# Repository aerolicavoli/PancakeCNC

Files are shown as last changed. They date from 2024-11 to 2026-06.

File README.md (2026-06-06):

# PancakeCNC

A fully custom, pancake-printing CNC platform. This repository collects the mechanical CAD, controller electronics, firmware, ground station tooling, and reference simulations that work together to lay down batter in precise paths.

## Table of Contents
- [Project Overview](#project-overview)
- [Repository Layout](#repository-layout)
- [Mechanical Platform](#mechanical-platform)
- [Electronics and PCB](#electronics-and-pcb)
- [Firmware (`Pancake_esp`)](#firmware-pancake_esp)
- [Ground Station Tools](#ground-station-tools)
- [Simulation & Analysis](#simulation--analysis)
- [Design Documentation](#design-documentation)
- [Command & Telemetry Protocol](#command--telemetry-protocol)
- [Development Environment](#development-environment)
- [License](#license)

## Project Overview
PancakeCNC is a learning platform for end-to-end mechatronics: mechanical design, PCB layout, embedded firmware, networking, and motion control. The goal is to dispense pancake batter using precise CNC motion profiles driven from a custom controller and cloud-connected command stream.

## Repository Layout
```
ControllerPCB/   KiCad project files for the controller board and manufacturing assets.
DesignDocs/      Engineering notes, diagrams, and BOMs.
GroundStation/   Python-based tooling for sending CNC commands and replaying G-code.
PancakeSim/      MATLAB scripts for kinematic studies and controller validation.
Pancake_esp/     ESP-IDF firmware for the ESP32-S3 based controller.
```

## Mechanical Platform
Motion is handled by a double-jointed planar arm that provides two rotational degrees of freedom so the dispenser can reach any point in the intended print envelope. Batter is metered with a peristaltic pump mounted at the arm's end effector.

The printable CAD for the hinges and pump assembly is currently tracked outside this repository; the focus here is on the control stack that drives the mechanism.

## Electronics and PCB
The `ControllerPCB` directory captures the KiCad design for the controller enclosure. Highlights include:

- ESP32-S3 compute module, GPIO breakout, and headers that feed external step/dir motor drivers sourced from the BOM.
- Power conditioning and 5 V level shifting for peripheral interfaces.
- Ready-to-fabricate assets: schematic (`ControllerPCB.kicad_sch`), layout (`ControllerPCB.kicad_pcb`), and generated BOM/gerbers.

## Firmware (`Pancake_esp`)
Firmware is built with ESP-IDF and lives under `Pancake_esp/`. Key modules:

- **Command Handling** (`CommandHandler.*`, `CNCOpCodes.h`): parses high-level instructions into motion primitives.
- **Motion Control** (`MotorControl.*`, `StepperMotor.*`, `TrapezoidalJog.*`, `ArchimedeanSpiral.*`): generates coordinated movements for the S0/S1 axes and pump.
- **Networking & Telemetry** (`InfluxDBCmdAndTlm.*`, `Telemetry.*`, `WifiHandler.*`): streams commands from InfluxDB and publishes runtime state.
- **Safety & UI** (`Safety.*`, `UI.*`): implements interlocks and emergency stop logic. A dedicated human interface is still a work in progress—commands flow through the InfluxDB bridge today.

To build the firmware you will need the ESP-IDF toolchain (v5.x recommended). After configuring credentials in `sdkconfig`/`Secret.h`, standard `idf.py build flash monitor` targets apply.

### Viewing ESP logs over the flash serial port (macOS)
The firmware keeps ESP-IDF logging active on the default serial sink, so anything emitted with `ESP_LOG*` can be viewed on the same USB serial device used for flashing.

1. List serial devices:
   ```bash
   ls /dev/cu.usb*
   ```
2. Open a monitor (replace the port with your device):
   ```bash
   idf.py -p /dev/cu.usbmodemXXXX monitor
   ```
   If you are outside an ESP-IDF shell, a simple fallback is:
   ```bash
   screen /dev/cu.usbmodemXXXX 115200
   ```
3. Exit monitor:
   - `idf.py monitor`: press `Ctrl+]`
   - `screen`: press `Ctrl+A`, then `K`, then `Y`

## Ground Station Tools
`GroundStation/CommandTerminal.py` is a CLI utility for sending commands through InfluxDB using a human-readable syntax. Example interactions:

```bash
python GroundStation/CommandTerminal.py e "Hello Pancake"
python GroundStation/CommandTerminal.py cnc_spiral CenterX_m=0.2 LinearSpeed_mps=0.05
python GroundStation/CommandTerminal.py run_file GroundStation/GCode/TestProgram.txt
```

Environment variables must be set to connect to InfluxDB:

- `INFLUXDB_URL`
- `INFLUXDB_TOKEN`
- `INFLUXDB_ORG`
- `INFLUXDB_CMD_BUCKET`

`GroundStation/GCode/` contains sample programs for testing complex pours.

## Simulation & Analysis
`PancakeSim/KinematicTestBed.m` is a MATLAB script for exercising the inverse kinematics and closed-loop control algorithms before they are deployed to hardware.

## Design Documentation
`DesignDocs/` aggregates system-level context:

- `DesignDiagrams.drawio` — block diagrams and signal flows.
- `BillOfMaterials.md` — hardware inventory and sourcing notes.
- `Channelization.md` — signal/channel mapping across subsystems.

## Command & Telemetry Protocol
Commands are binary packets exchanged through InfluxDB and consumed by the firmware.

### Frame Layout
| Byte Index | Field | Size | Description |
|---|---|---|---|
| `[0]` | **Op Code** | 1 byte | Instruction identifier |
| `[1]` | **Length** | 1 byte | Number of payload bytes (*n*) |
| `[2..n+1]` | **Payload** | *n* bytes | Instruction-specific data |

### Firmware Opcodes
Immediate commands bypass the CNC queue:

- `0x01` — `pause`
- `0x02` — `resume`
- `0x03` — `stop`
- `0x69` — `echo`

Queued motion & configuration commands include:

- `0x11` — `cnc_spiral`
- `0x12` — `cnc_jog`
- `0x13` — `wait`
- `0x14` — `cnc_sine`
- `0x15` — `cnc_constant_speed`
- `0x16` — `set_motor_limits`
- `0x17` — `set_pump_constant`
- `0x18` — `cnc_arc`
- `0x19` — `pump_purge`

Payloads are little-endian C structs (refer to headers under `Pancake_esp/main/`). The CLI automatically translates key-value inputs into the correct binary layouts. `pump_purge` accepts a signed `pumpSpeed_degps`; use a negative value, such as `pump_purge pumpSpeed_degps=-300 duration_ms=500`, to reverse the pump and pull batter back before stopping.

### Round-Trip Testing
`GroundStation/RoundtripTest.py` can send a command and fetch the recorded response, verifying connectivity and serialization. If environment variables are missing it will attempt to source `Secret.sh`.

## Development Environment
- **Firmware**: ESP-IDF (requires Python, CMake, Ninja). Install dependencies per Espressif documentation.
- **Ground Station**: Python 3.10+. Install requirements (if a `requirements.txt` is added) or run directly with the standard library and `influxdb-client`.
- **Mechanical/Electrical CAD**: KiCad 7.x for PCB edits, CAD/CAM packages for STL manipulation.

## License
This project is currently distributed without an explicit license; treat the assets as freely reusable unless noted otherwise in specific subdirectories.

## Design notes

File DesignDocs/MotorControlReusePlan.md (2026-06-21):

# Motor Control Complexity and Reuse Improvement Plan

## Purpose

`MotorControlTask` currently combines queue handling, command decoding, guidance selection, motion solving, pump control, stop handling, motor output, limit switch handling, and telemetry publication in one long control loop. The goal of this plan is to keep the timing-critical loop small and predictable while moving reusable policies into focused components that can be tested without FreeRTOS or motor hardware.

## Current Complexity Drivers

1. **Many responsibilities in one task**
   - The task owns immediate command handling, queued configuration commands, motion opcode dispatch, target generation, cartesian-to-angle conversion, speed limiting, pump decisions, telemetry copies, and limit switch reactions.
   - Safety hold behavior is repeated in multiple branches, including explicit stop handling and out-of-bounds handling.

2. **Implicit shared state**
   - Loop state is spread across local variables (`instructionComplete`, `pumpThisMode`, `cmdViaAngle`, purge fields, target angles, target position, commanded speeds) and globals (`Pos_m`, `Vel_mps`, `Target_m`, telemetry data, `CNCEnabled`, `EStopActive`).
   - It is difficult to determine which fields must be reset when a command completes, pauses, stops, faults, or trips a limit switch.

3. **Opcode dispatch is repetitive**
   - Each guidance command repeats the same payload-length validation, `memcpy`, `ApplyConfig`, `currentGuidance` assignment, pump flag handling, and logging pattern.
   - Adding a new motion type requires editing the central switch and risks changing unrelated behavior.

4. **Hardware and policy are tightly coupled**
   - Speed computation, pump flow policy, and limit switch behavior are interleaved with direct `StepperMotor` calls and FreeRTOS queues.
   - This limits reuse from host-side tests and makes regression tests harder to write.

5. **Mixed coordinate command paths**
   - Cartesian guidance and angle guidance share state but diverge late in the loop.
   - Angle-specific completion and speed limiting for go-to-angle is embedded in the task instead of being a reusable angle-mode controller.

## Target Design

Refactor toward a small orchestration loop backed by reusable components:

```text
MotorControlTask
  ├── MotorControlState          // all mutable loop state in one struct
  ├── MotorCommandRouter         // now queue + cnc queue classification
  ├── GuidanceRegistry           // opcode -> typed guidance adapter
  ├── MotionPlanner              // target -> motor angle/speed command
  ├── PumpController             // print-flow and purge policy
  ├── SafetyHoldController       // pause/stop/fault/limit switch holds
  ├── MotorDriverSet             // S0/S1/pump StepperMotor facade
  └── TelemetryPublisher         // copies a state snapshot to telemetry
```

The end state should let `MotorControlTask` read telemetry, route commands, ask the active guidance for a target, ask the planner and pump controller for commands, apply safety overrides, write motor outputs, publish telemetry, and sleep.

## Behavior That Must Be Preserved

- Jog commands must remain able to request motion either with the pump on or with the pump off. The refactor should keep `CNC_JOG_OPCODE`'s `PumpOn` payload field as an explicit per-command policy, not collapse jog into a single default pump behavior.

## Refactoring Principles

- **Keep behavior-preserving steps small.** Each phase should compile and run tests before moving to the next phase.
- **Introduce seams before changing behavior.** First move existing code into functions/classes with equivalent inputs and outputs; then improve internals.
- **Prefer data ownership over parallel variables.** Replace groups of related locals with named structs and reset/apply helper functions.
- **Make policies host-testable.** Components that do not require ESP-IDF or GPIO should live behind simple interfaces and have unit tests under `Tests/`.
- **Use adapters for legacy guidance classes.** Avoid rewriting all guidance classes at once; wrap them in a common registry/factory pattern. Adapter metadata should preserve command-specific options such as jog's pump-on/pump-off selection.
- **Centralize stop/hold semantics.** All pause, stop, fault, unreachable-target, and limit-switch paths should share one hold command application path.

## Phased Plan

### Phase 1: Name and isolate loop state

1. Add a `MotorControlState` struct that owns the current position, velocity, target position, target angles, commanded speeds, active guidance pointer, completion flag, pump mode, purge state, command mode, pause state, and force-update flag.
2. Move repeated application of `MotionHoldCommand` into a single `ApplyHoldCommand(MotorControlState&, const MotionHoldCommand&)` helper.
3. Replace scattered local resets with state methods such as `IdleAtCurrentPosition(...)`, `StopPurge()`, and `CompleteInstruction()`.
4. Keep the existing globals as compatibility aliases initially, but update them from the state snapshot in one place.

**Success criteria**
- The main task has fewer independent local variables.
- Stop and out-of-bounds paths call the same hold-application helper.
- Existing behavior remains unchanged.

### Phase 2: Extract command routing and configuration handling

1. Create a `MotorCommandRouter` with methods for:
   - consuming immediate pause/resume/stop commands;
   - draining queued CNC commands when requested;
   - consuming non-motion configuration commands at the head of the CNC queue;
   - returning the next motion command only when the controller is ready.
2. Move config-command handlers into named methods (`ApplyMotorLimits`, `ApplyPumpConstant`, `ApplyAccelScale`, `StartPumpPurge`) with explicit payload validation.
3. Define a small `MotorControlConfig` struct for tunable values such as `pumpConstant_degpm`, `accelScale`, and position tolerance.
4. Validate payload lengths against command-specific expected sizes rather than open-ended checks where possible, unless a command intentionally supports extension.

**Success criteria**
- The task loop no longer contains queue peeking/parsing details.
- Config behavior is independently testable with synthetic payloads.
- Unknown or malformed commands produce one consistent error path.

### Phase 3: Replace central opcode switch with a guidance registry

1. Introduce a `GuidanceRegistry` that owns the existing guidance instances and maps each opcode to a descriptor:
   - opcode;
   - expected payload size;
   - pump policy source (`AlwaysOff`, `AlwaysOn`, or `FromPayload`);
   - typed apply function;
   - pointer/reference to the guidance object.
2. Factor the repeated validate/copy/apply/start pattern into one generic command loader.
3. Preserve special cases, such as jog's `PumpOn` flag and go-to-angle's angle-command mode, in the descriptor/adaptor instead of the main loop.
4. Add a lightweight unit test that submits representative opcode payloads and verifies the selected guidance, command mode, and pump policy. Include both `PumpOn=0` and `PumpOn=1` jog payloads.

**Success criteria**
- Adding a guidance type requires adding a descriptor and guidance instance, not editing a large switch.
- Payload validation and logging are uniform for all guidance commands.
- `MotorControlTask` only asks the registry to start a motion command.

### Phase 4: Extract motion planning

1. Create a `MotionPlanner` with explicit input and output structs:
   - inputs: current motor telemetry, current cartesian state, target position, guidance command mode, active guidance metadata, limits, accel scale;
   - outputs: target angles, S0/S1 commanded speeds, instruction-complete override, hold/fault request.
2. Move `WrapAngleDeltaDeg` and `ComputeDecelLimitedSpeedDegps` into the planner or a reusable motion math module.
3. Split planning by mode:
   - `PlanCartesianTarget` performs `CartToAng`, reachability checks, and speed limiting;
   - `PlanAngleTarget` handles go-to-angle target angles, tolerance, completion, and speed limiting;
   - `PlanIdleHold` generates zero-speed angle-mode hold commands.
4. Represent reachability failures as a planner status instead of stopping directly inside planning code; the task or safety controller applies the hold.

**Success criteria**
- Cartesian and angle command paths are explicit and separately testable.
- Out-of-bounds handling reuses the same stop/hold path as immediate stop.
- Speed limiting can be validated with host-side tests.

### Phase 5: Extract pump policy

1. Create a `PumpController` that owns purge state and computes pump speed from:
   - emergency-stop state;
   - instruction-active state;
   - active command pump policy, including jog's per-command pump-on/pump-off choice;
   - target error magnitude;
   - current cartesian velocity;
   - configured pump constant.
2. Give purge override a clear priority over normal print-flow mode while still respecting pause/stop.
3. Replace bare purge locals with methods such as `StartPurge(speed, duration)`, `CancelPurge()`, and `Update(period_ms)`.
4. Add tests for normal printing, no-pump modes, position tolerance gating, purge timeout, and pause cancellation.

**Success criteria**
- Pump behavior is no longer interleaved with cartesian planning.
- Pump policy can be reused by future print modes without touching motor planning, while still allowing jogs to choose whether they dispense.
- Purge state transitions are covered by tests.

### Phase 6: Isolate motor hardware access

1. Create a `MotorDriverSet` facade around S0, S1, and pump motors.
2. Move repeated target-speed and update-speed calls into `ApplyMotorSpeeds(const MotorSpeedCommand&, bool forceUpdate)`.
3. Move motor limit updates into facade methods that accept motor IDs and all-motors broadcasts.
4. Add a fake motor-driver implementation for unit tests, or define a minimal interface where host tests can assert commanded speeds without ESP timers.

**Success criteria**
- Motor output application is one method call from the task loop.
- Config commands no longer capture concrete `StepperMotor` objects in local lambdas.
- Host tests can exercise router/planner/controller code without real motors.

### Phase 7: Centralize telemetry publishing and synchronization

1. Create a `TelemetryPublisher` that takes a `MotorControlState` snapshot and motor telemetry snapshot.
2. Keep all writes to `TelemetryData` in one function.
3. Decide whether telemetry needs a FreeRTOS critical section, mutex, or double-buffered snapshot, then apply it in the publisher only.
4. Include pause/active-guidance/pump-purge status fields if the telemetry model supports them later.

**Success criteria**
- The task loop no longer manually copies every telemetry field.
- Thread-safety changes are isolated to one publisher.
- Future telemetry fields can be added without changing planning logic.

### Phase 8: Limit switch and safety integration

1. Move limit switch handling into `SafetyHoldController` or a dedicated `LimitSwitchController`.
2. Make the limit-switch result explicit: directional inhibit, zero request, instruction-complete request, and optional queue drain/fault state.
3. Use the same state transition methods for limit-switch stops as for pause/stop/faults.
4. Add tests that assert the correct motor receives the correct directional inhibit and zero request.

**Success criteria**
- Limit switch policy is not mixed with telemetry publication.
- Every safety-related transition has one clearly named path.
- Safety behavior can be reviewed without reading the entire motor loop.

## Suggested Intermediate File Layout

```text
Pancake_esp/main/
  MotorControl.cpp              // short FreeRTOS orchestration task
  MotorControl.h
  MotorControlState.h           // state and command structs
  MotorCommandRouter.h/.cpp     // queue parsing and command classification
  GuidanceRegistry.h/.cpp       // opcode-to-guidance adapters
  MotionPlanner.h/.cpp          // reusable target/speed planning
  PumpController.h/.cpp         // reusable pump and purge policy
  MotorDriverSet.h/.cpp         // StepperMotor facade
  TelemetryPublisher.h/.cpp     // TelemetryData snapshot writes
```

Start with header-only structs and small `.cpp` files only where necessary. If ESP-IDF include dependencies make host tests hard, keep pure policy headers free of FreeRTOS and GPIO headers.

## Testing Strategy

1. **Host unit tests first**
   - Add tests for `ComputeDecelLimitedSpeedDegps`, angle wrapping, cartesian reachability status, pump purge timing, and command payload validation.
2. **Regression tests around existing guidance**
   - Use existing guidance classes directly to verify registry selection does not alter target generation.
3. **Fake queue and fake motor tests**
   - Test command routing and motor output application without FreeRTOS timers or GPIO.
4. **On-device smoke tests after each major phase**
   - Pause/resume/stop.
   - Jog with pump off/on.
   - Spiral/arc/rectangle print commands.
   - Go-to-angle completion tolerance.
   - Pump purge during idle and during active motion.
   - Limit switch trip and reset behavior.

## Recommended Implementation Order

1. `MotorControlState` and hold-command application helper.
2. `PumpController`, because it is low-risk and easy to test.
3. `MotionPlanner`, because it removes the highest-risk math from the task loop.
4. `GuidanceRegistry`, because it reduces opcode-switch churn after planner seams exist.
5. `MotorCommandRouter`, because it becomes simpler once config and motion targets have homes.
6. `MotorDriverSet` and `TelemetryPublisher`, because these are mostly integration cleanup.
7. `LimitSwitchController`/safety cleanup, after the hold path is proven.

## Risks and Mitigations

- **Risk: behavior changes during extraction.** Mitigate by snapshotting current behavior with tests before changing policy internals.
- **Risk: ESP-IDF dependencies leak into host tests.** Mitigate with pure data structs and facades around queues, GPIO, and `StepperMotor`.
- **Risk: registry descriptors hide important special cases.** Mitigate by making special policy fields explicit (`pumpPolicy`, `commandMode`, `completionPolicy`) and testing each opcode.
- **Risk: too many tiny classes too early.** Mitigate by extracting functions and structs first, then promoting them to classes only when there is clear state or interface ownership.

## Definition of Done

The refactor is complete when:

- `MotorControlTask` is primarily orchestration and fits on one screen or close to it.
- All pause/stop/fault/limit-switch holds share one state transition path.
- Adding a new guidance opcode does not require duplicating payload-validation boilerplate.
- Motion math and pump policy have host-side unit coverage.
- Motor hardware access and telemetry writes are isolated behind narrow interfaces.
- Existing on-device motion behavior is preserved unless a change is intentionally documented.

## Refactor Progress

This checklist tracks what has actually been completed in code, not just what has been planned.

- [x] **Phase 1: Name and isolate loop state** — Complete.
  - [x] Added `MotorControlState` to own current position, velocity, target position, target angles, commanded speeds, active guidance, completion state, pump state, purge state, command mode, pause state, and force-update state.
  - [x] Added shared state helpers, including `ApplyHoldCommand`, `IdleAtCurrentPosition`, `StopPurge`, `CompleteInstruction`, and `StartInstruction`.
  - [x] Replaced repeated stop/out-of-bounds hold assignments with the shared hold application path.
  - [x] Kept existing position/target/pause globals synchronized from the state snapshot for compatibility.
- [x] **Phase 2: Extract command routing and configuration handling** — Complete.
  - [x] Added `MotorCommandRouter` to consume immediate pause/resume/stop commands, drain the CNC queue, consume head-of-queue configuration commands, and return the next motion command only when the state is ready.
  - [x] Moved configuration handlers into named router methods for motor limits, pump constant, acceleration scale, and pump purge.
  - [x] Added `MotorControlConfig` for tunable pump constant, acceleration scale, and position tolerance.
  - [x] Configuration handlers now validate command-specific payload lengths exactly before applying payload contents.
- [x] **Phase 3: Replace central opcode switch with a guidance registry** — Complete.
  - [x] Added `GuidanceRegistry` with opcode descriptors, expected payload sizes, typed apply functions, guidance pointers, explicit pump policy sources, and command-mode metadata.
  - [x] Replaced the repeated guidance payload validate/copy/apply/start switch with a generic registry loader in `MotorControlTask`.
  - [x] Preserved jog pump selection by resolving `CNC_JOG_OPCODE` pump behavior from the `JogConfig::PumpOn` payload field, including both pump-off and pump-on unit coverage.
  - [x] Moved command-mode selection into registry metadata so go-to-angle, sine, and constant-speed commands are started as angle-mode commands by descriptor rather than by switch-case side effect.
  - [x] Added unit coverage for registry selection, pump policy, command-mode metadata, invalid payload length handling, and unknown opcode handling.
- [ ] **Phase 4: Extract motion planning** — Not started. Cartesian-to-angle conversion, reachability handling, and angle-mode speed limiting still live in `MotorControlTask`.
- [ ] **Phase 5: Extract pump policy** — Not started. Normal pump-speed calculation and purge timing still live in `MotorControlTask`, although Phase 3 now makes the active command's pump-policy source explicit.
- [ ] **Phase 6: Isolate motor hardware access** — Not started. Motor speed commands and limit updates still call `StepperMotor` directly from the task/router integration.
- [ ] **Phase 7: Centralize telemetry publishing and synchronization** — Not started. Telemetry writes are still performed directly in the task loop.
- [ ] **Phase 8: Limit switch and safety integration** — Not started. Limit switch handling is still interleaved with telemetry and motor-control logic.

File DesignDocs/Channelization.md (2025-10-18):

# Pancake CNC – Channelization Rev2

This document describes the channelization for the Pancake CNC.
It details signal routing from the CNC controller, through the PCB,  
through ports on the PCB, and to the end effectors.

This pertains to the second revision of the Pancake CNC PCB.

---

| End User | Direction | PCB Port | Box Port | Corrected Box Port Position | Position | Internal Wire | Conditioning | ESP32 Pin | ESP32 Pin Function | Pi PIN |
|:---|:---|:---|:---|:---|:---|:---|:---|:---|:---|:---|
| Servo Control | Output | Aux DSub (Warning, flipped connector) | DSUB7 | 8 | 7 | Brown | 5V Level Shift | GPIO12 | | |
| S1 Limit | Input | Aux DSub (Warning, flipped connector) | DSUB1 | 5 | 1 | Blue Stripe | None | GPIO15 | | |
| S0 Limit | Input | Aux DSub (Warning, flipped connector) | DSUB3 | 3 | 3 | Green Strip | None | GPIO16 | | |
| Pump Pulse | Output | JST to Driver Zone | | | 1 | | None | GPIO04 | pulse | |
| Pump Dir | Output | JST to Driver Zone | | | 2 | | None | GPIO05 | dir | |
| Pump Enable | Output | JST to Driver Zone | | | 3 | | None | GPIO06 | enable | |
| S0 Pulse | Output | JST to Driver Zone | | | 4 | | None | GPIO07 | pulse | |
| S0 Dir | Output | JST to Driver Zone | | | 5 | | None | GPIO08 | dur | |
| S1 Pulse | Output | JST to Driver Zone | | | 6 | | None | GPIO09 | pulse | |
| S1 Dir | Output | JST to Driver Zone | | | 7 | | None | GPIO10 | dir | |
| S0/S1 Enable | Output | JST to Driver Zone | | | 8 | | None | GPIO14 | enbable | |
| Input Pot X | Input | JST to UI Zone | | | | | None | GPIO01 | ADC1_CH0 | |
| Input Pot Y | Input | JST to UI Zone | | | | | None | GPIO02 | ADC1_CH1 | |
| Flip Switch 1 | Output | JST to UI Zone | | | | | | GPIO18 | | |
| Control Box LED Address | Output | JST to UI Zone | | | | | 5V Level Shift | GPIO21 | | |
| Flip Switch 2 | Output | JST to UI Zone | | | | | | GPIO38 | | |
| Flip Switch 3 | Output | JST to UI Zone | | | | | | GPIO45 | | |
| Flip Switch 4 | Output | JST to UI Zone | | | | | | GPIO46 | | |
| Flip Switch 5 | Output | JST to UI Zone | | | | | | GPIO47 | | |
| Flip Switch 6 | Output | JST to UI Zone | | | | | | GPIO48 | | |
| Control Box Temp | Input | None | | | | | | GPIO03 | ADC1_CH3 | |
| PCB Alive LED | Output | None | | | | | None | GPIO17 | | |
| Pi Serial Data In | Input | Pi JST | | | 1 | | | GPIO11 | FSPID | |
| Pi Serial Data Out | Serial | Pi JST | | | 2 | | | GPIO13 | FSPIQ | |
| Reserved | Reserved | Pi JST | | | 3 | | | GPIO18 | | |
| S0 White | Output | Motor Control DSub | DSUB15 | | 15 | Blue Stripe | | S0B+ | | |
| S0 Black | Output | Motor Control DSub | DSUB15 | | 14 | Blue Solid | | S0A- | | |
| S0 Red | Output | Motor Control DSub | DSUB15 | | 13 | Brown Stripe | | S0B- | | |
| S0 Green | Output | Motor Control DSub | DSUB15 | | 12 | Brown Solid | | S0A+ | | |
| Pump White | Output | Motor Control DSub | DSUB15 | | 11 | Blue Stripe | | PumpB+ | | |
| Pump Black | Output | Motor Control DSub | DSUB15 | | 10 | Blue Solid | | PumpA- | | |
| Pump Red | Output | Motor Control DSub | DSUB15 | | 6 | Brown Stripe | | PumpB- | | |
| Pump Green | Output | Motor Control DSub | DSUB15 | | 5 | Brown Solid | | PumpA+ | | |
| S1 White | Output | Motor Control DSub | DSUB15 | | 4 | Blue Stripe | | S1B+ | | |
| S1 Black | Output | Motor Control DSub | DSUB15 | | 3 | Blue Solid | | S1A- | | |
| S1 Red | Output | Motor Control DSub | DSUB15 | | 2 | Brown Stripe | | S1B- | | |
| S1 Green | Output | Motor Control DSub | DSUB15 | | 1 | Brown Solid | | S1A+ | | |
| Ground | | Aux DSub (Warning, flipped connector) | DSUB2 | 4 | 2 | Blue Solid | | | | |
| Ground | | Aux DSub (Warning, flipped connector) | DSUB4 | 2 | 4 | Green Solid | | | | |
| Ground | | Aux DSub (Warning, flipped connector) | DSUB9 | 6 | 9 | Orange Stripe | | | | |
| Reserved | | Aux DSub (Warning, flipped connector) | DSUB5 | 1 | 5 | | | | | |
| Reserved | | Aux DSub (Warning, flipped connector) | DSUB6 | 9 | 6 | | | | | |
| 5V Servo Power | Output | Aux DSub (Warning, flipped connector) | DSUB8 | 7 | 8 | Orange Solid | | | | |

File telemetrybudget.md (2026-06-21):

# Telemetry Budget

This document summarizes the registered telemetry points, their update rates, and the expected InfluxDB line-protocol payload size per transmit period.

## Scheduling model

Telemetry aggregation runs once every `BUFFER_ADD_PERIOD_MS` (`1000 ms`, or `1 Hz`). The transmit task runs every `TRANSMITPERIOD_MS` (`900 ms`) and sends whatever has accumulated in the working telemetry buffer since the previous transmit attempt.

Each telemetry point is registered with its own period. There are no separate runtime buckets; the aggregate task walks the registry and publishes any point whose configured period has elapsed.

Log lines are also added to the same telemetry buffer when present, but they are event-driven and are **not** included in the fixed-rate budget below.

## Fixed-rate telemetry points

| Rate | Period | Points | Measurements |
| --- | ---: | ---: | --- |
| `1 Hz` | `1000 ms` | 10 | `tipPos_X_m`, `tipPos_Y_m`, `targetPos_X_m`, `targetPos_Y_m`, `S0_Speed_degps`, `S0_TargetSpeed_degps`, `S1_Speed_degps`, `S1_TargetSpeed_degps`, `Pump_Speed_degps`, `Pump_TargetSpeed_degps` |
| `0.25 Hz` | `4000 ms` | 8 | `targetPos_S0_deg`, `targetPos_S1_deg`, `plannedTarget_S0_deg`, `plannedTarget_S1_deg`, `plannedDelta_S0_deg`, `plannedDelta_S1_deg`, `S0_Pos_deg`, `S1_Pos_deg` |
| `0.05 Hz` | `20000 ms` | 13 | `espTemp_C`, `limitBlocked_S0`, `limitBlocked_S1`, `S0_LimitSwitch`, `S1_LimitSwitch`, `cartesianBoundaryCorner0_X_m`, `cartesianBoundaryCorner0_Y_m`, `cartesianBoundaryCorner1_X_m`, `cartesianBoundaryCorner1_Y_m`, `cartesianBoundaryCorner2_X_m`, `cartesianBoundaryCorner2_Y_m`, `cartesianBoundaryCorner3_X_m`, `cartesianBoundaryCorner3_Y_m` |

## Size assumptions

The fixed-rate byte estimates assume the current line protocol format:

```text
<measurement>,location=us-midwest data=<value> <timestamp>\n
```

Assumptions used for the estimate:

- `<value>` is formatted by `%.5f`; the estimate uses `0.00000` (`7` bytes). Negative values or values with more integer digits add bytes.
- `<timestamp>` is a 13-digit millisecond timestamp.
- One newline is included per telemetry point.
- HTTP headers, TLS overhead, TCP/IP framing, and event-driven log telemetry are excluded.

## Payload budget by cadence

| Cadence contribution | Points | Bytes per cadence event | Average bytes per second |
| --- | ---: | ---: | ---: |
| `1 Hz` points | 10 | ~632 B every 1 s | ~632.00 B/s |
| `0.25 Hz` points | 8 | ~514 B every 4 s | ~128.50 B/s |
| `0.05 Hz` points | 13 | ~915 B every 20 s | ~45.75 B/s |
| **Total fixed-rate average** | 31 | N/A | **~806.25 B/s** |

## Expected bytes per transmit period

Because the transmit task runs every `900 ms` and aggregation runs every `1000 ms`, not every transmit tick contains a new aggregate sample. Over a long-running average, fixed-rate telemetry produces:

```text
806.25 B/s * 0.9 s/transmit period = ~725.6 B/transmit period
```

Representative fixed-rate transmit payloads are:

| Transmit payload case | Approximate payload bytes | Notes |
| --- | ---: | --- |
| Empty fixed-rate transmit | 0 B | Possible when the 900 ms transmit task wakes before a new 1000 ms aggregate cycle has added data. |
| 1 Hz-only aggregate | ~632 B | Most aggregate cycles. |
| 1 Hz + 0.25 Hz aggregate | ~1,146 B | Every 4 seconds. |
| 1 Hz + 0.25 Hz + 0.05 Hz aggregate | ~2,061 B | Every 20 seconds, when all registered periods align. |

The fixed telemetry buffer size is `6000 B` with a warning threshold of `5500 B`, so the largest fixed-rate aligned payload is currently about `2.1 kB`, leaving roughly `3.9 kB` of buffer headroom for queued log lines and larger-than-assumed numeric values.

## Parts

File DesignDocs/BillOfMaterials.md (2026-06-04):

# Pancake CNC – Bill of Materials (BOM)

This document lists the **Bill of Materials (BOM)** for the Pancake CNC project.  
It includes all electrical, mechanical, and structural components required for assembly.  
Each line details part numbers, sources, quantities, and other relevant specifications.

---

| Pump | Notes | Source URL |
|:---|:---|:---|
| Part | Quantity | Source |
| tubing | 2 | https://www.mcmaster.com/5894K37/ |
| m3x10 | | https://www.mcmaster.com/91290A115/ |
| m4x20 | | |
| Bearings | 5 | https://www.servocity.com/1600-series-non-flanged-ball-bearing-4mm-id-x-16mm-od-4mm-thickness-2-pack/ |
| hub | | https://www.servocity.com/1314-series-steel-set-screw-hub-5mm-bore/ |
| Spacers | | https://www.servocity.com/1502-series-4mm-id-spacer-6mm-od-1mm-length-4-pack/ |
| Stepper | 1 | https://www.mcmaster.com/4798n12/ |
| CNC | | |
| Part | Quantity | Source |
| 30x30 | 1 | https://8020.net/30-3030.html |
| 60x30 | 1 | https://8020.net/30-3060.html |
| corner bracket | 2 | https://8020.net/30-4303.html |
| tlsot bracket | 2 | https://8020.net/30-4305.html |
| tslot 2x2 | 2 | https://8020.net/30-4367.html |
| NEMA-17 Motor Mount | 2 | https://www.amazon.com/Mrosnail-Stepper-Motor-Mounting-Bracket/dp/B0CRQCT8J5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 |
| fixed pulley | 1 | https://www.mcmaster.com/1277N51/ |
| motor gear | 1 | https://www.mcmaster.com/2664N334/ |
| stepper motor | 2 | https://www.mcmaster.com/4798N12/ |
| Cable ties | 6 | https://www.mcmaster.com/5537T835/ |
| t nuts | 5 | https://www.mcmaster.com/6000N201/ |
| m4 nut | 1 | https://www.mcmaster.com/90592A090/ |
| m4 x 10mm | 1 | https://www.mcmaster.com/92095A190/ |
| Threaded insert | 2 | https://www.mcmaster.com/94459A422/ |
| Bearings | 2 | https://www.servocity.com/1-4-id-x-3-8-od-flanged-ball-bearing-2-pack/ |
| short chan | 1 | https://www.servocity.com/1120-series-u-channel-1-hole-48mm-length/ |
| long chan | 1 | https://www.servocity.com/1121-series-low-side-u-channel-9-hole-240mm-length/ |
| Gussets | 3 | https://www.servocity.com/1204-series-gusseted-angle-mount-1-1-2-pack/ |
| Hub | 2 | https://www.servocity.com/1314-series-steel-set-screw-hub-1-4-bore/ |
| fixed gear | 1 | https://www.servocity.com/2302-series-aluminum-mod-0-8-hub-mount-gear-14mm-bore-108-tooth/ |
| motor pulley | 1 | https://www.servocity.com/5mm-10-tooth-pinion-pulley/ |
| 1/4in shaft | | |
| 1/4 in collars | | |
| Stop Tower | 1 | https://www.servocity.com/1109-series-gorail-120mm-length/ |
| timing belt | 1 | https://www.servocity.com/8-40t-3-8-wide-xl-timing-belt/ |
| Avionics | | |
| Part | Quantity | Source |
| Motor driver | 3 | https://www.amazon.com/UsongShine-Stepper-Controller-Arduino-Printer/dp/B07HHS14VQ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 |
| limit switches | 2 | |
| Flight computer | 1 | |
| Avionics box | | amazon.com/dp/B0CTJX2Q43?ref=ppx_yo2ov_dt_b_fed_asin_title |
| Power supply | | |
| GPIO Ribbon Calbe | | https://www.adafruit.com/product/1988 |
| Level Shifter | | https://www.digikey.com/en/products/detail/nexperia-usa-inc/LSF0204PWJ/12808380 |
| 3v Reg | | https://www.digikey.com/en/products/detail/evvo/AMS1117-3-3/22482148 |
| 5v Reg | | https://www.digikey.com/en/products/detail/texas-instruments/LM1084IS-5-0-NOPB/363552 |
| Resistor 805 | | https://www.digikey.com/en/products/detail/panasonic-electronic-components/ERJ-P06F1002V/398270 |
| Caps 805 | | https://www.digikey.com/en/products/detail/samsung-electro-mechanics/CL21A106MQFNNNE/3886956 |
| Temp Sensor | | https://www.digikey.com/en/products/detail/texas-instruments/TMP236A4DCKR/9562764 |
| 10 pos driver JST | | https://www.digikey.com/en/products/detail/jst-sales-america-inc/10JQ-BT/4918700 |
| Low Voltage DSub | | https://www.digikey.com/en/products/detail/assmann-wsw-components/A-DF-09-A-KG-T4S/1241802 |
| High Voltage DSub | | https://www.digikey.com/en/products/detail/norcomp-inc/171-015-203L031/858129 |
| Pi JST | | B5B-XH-A |
| Momentary Switch | | https://www.digikey.com/en/products/detail/c-k/PTS526-SK15-SMTR2-LFS/10056626 |

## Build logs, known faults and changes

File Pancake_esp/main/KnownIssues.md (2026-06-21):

KnownIssues.md

* cnc rectange, or stop causes a reset
* When the CNC reboots, it loses its zero.  I would like the state to be periodically written to eeprom and read in on reset.
* CNC should go to home after homing operation, not to zero zeero.

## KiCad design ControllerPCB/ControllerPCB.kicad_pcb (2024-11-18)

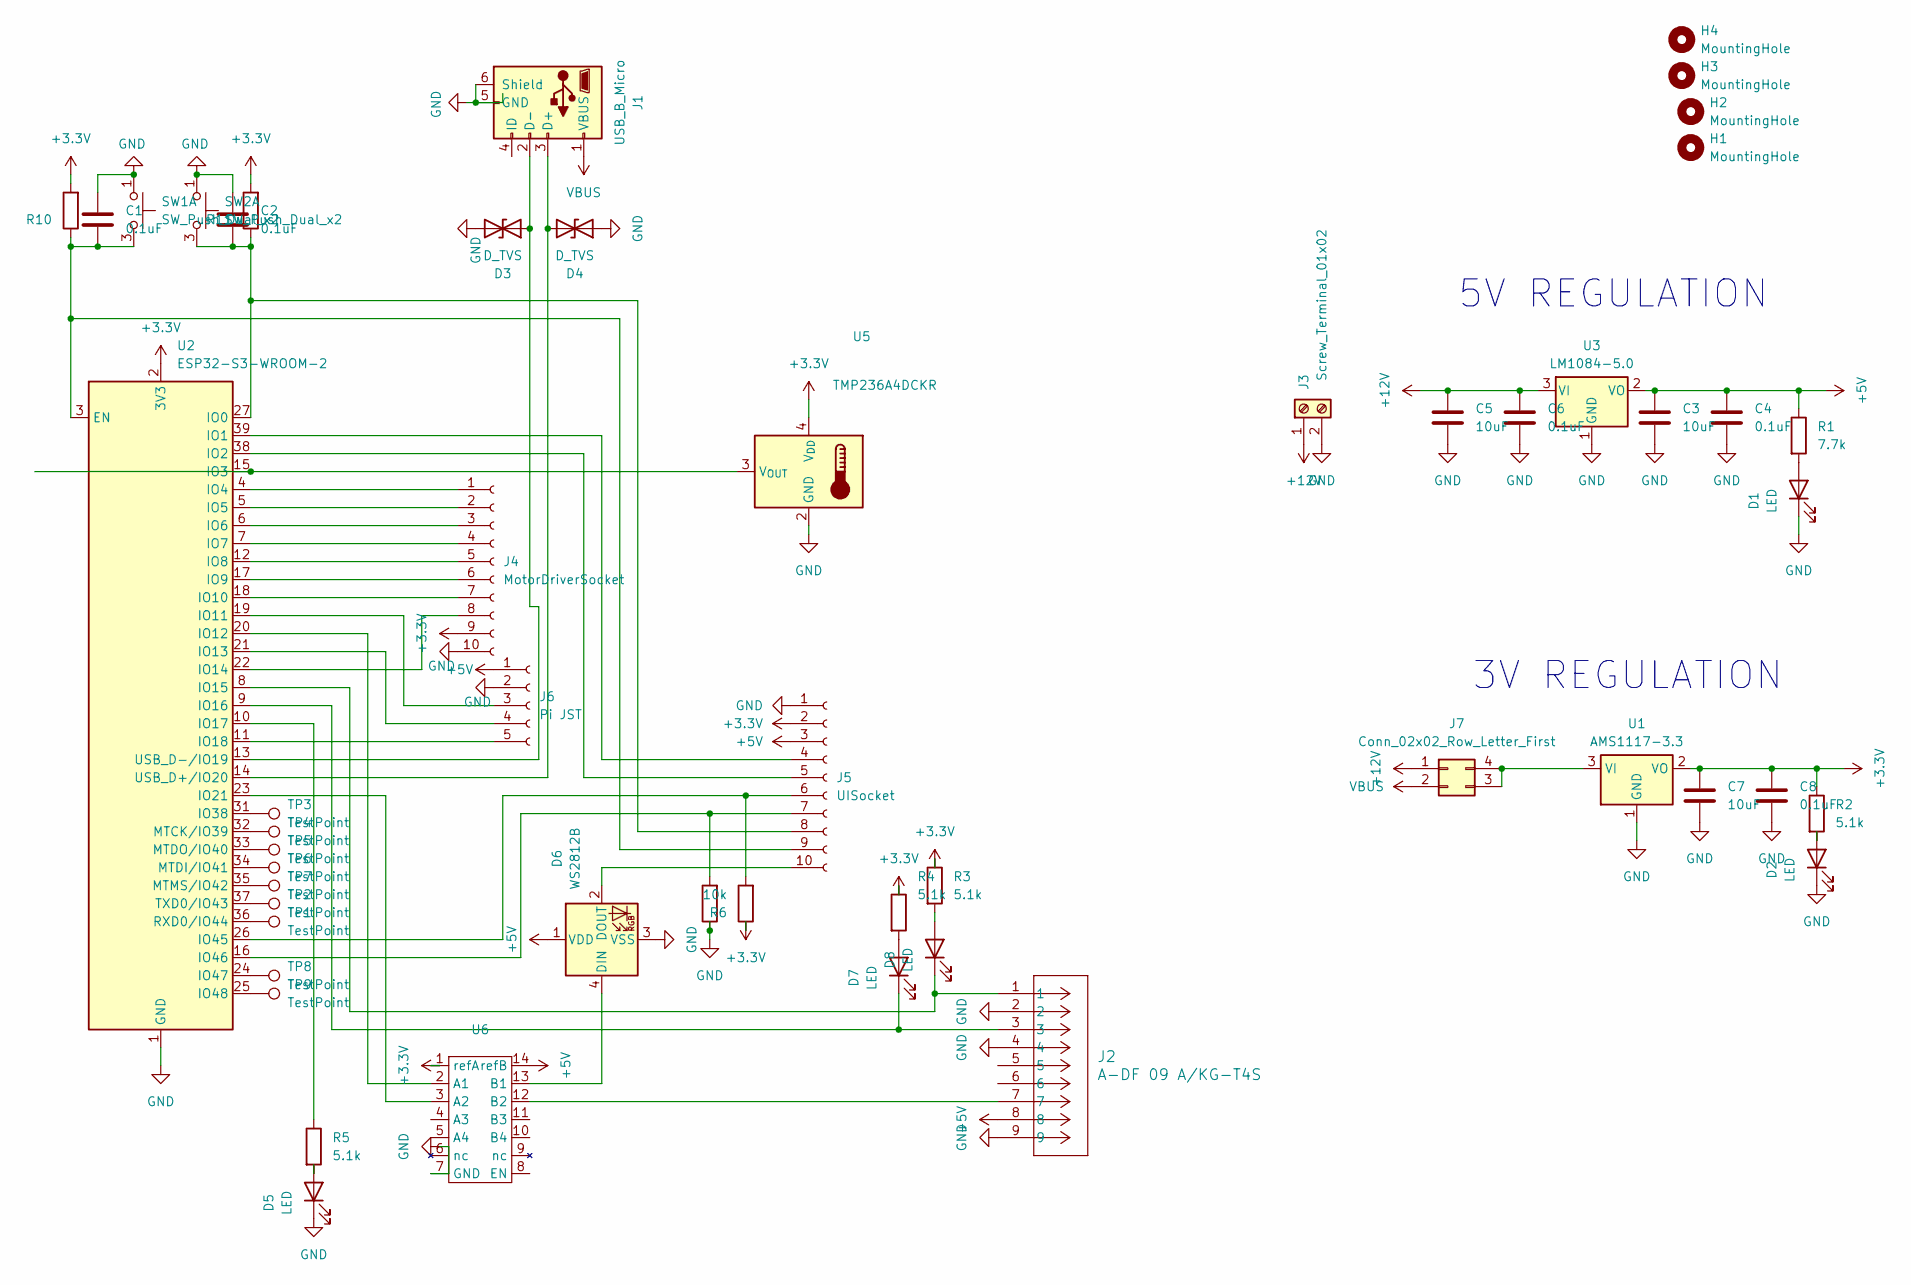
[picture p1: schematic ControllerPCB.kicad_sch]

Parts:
C1, C2, C4, C6, C8: 0.1uF; C_0805_2012Metric_Pad1.18x1.45mm_HandSolder
C3, C5, C7: 10uF; C_0805_2012Metric_Pad1.18x1.45mm_HandSolder
D1, D2, D5, D7, D8: LED; LED_0805_2012Metric_Pad1.15x1.40mm_HandSolder
D3, D4: D_TVS; D_SOD-323_HandSoldering
D6: WS2812B; LED_WS2812B_PLCC4_5.0x5.0mm_P3.2mm
H1, H2, H3, H4: MountingHole; MountingHole_3.2mm_M3
J1: USB_B_Micro; USB_Micro-AB_Molex_47590-0001
J2: A-DF 09 A/KG-T4S; MyDSUBASSMANN_A-DF_09_A_KG-T4S
J3: Screw_Terminal_01x02; TerminalBlock_TE_282834-2_1x02_P2.54mm_Horizontal
J4: MotorDriverSocket; 10JQ-BT_JST
J5: UISocket; 10JQ-BT_JST
J6: Pi JST; JST_EH_B5B-EH-A_1x05_P2.50mm_Vertical
J7: Conn_02x02_Row_Letter_First; PinSocket_2x02_P2.54mm_Vertical
R1: 7.7k; R_0805_2012Metric_Pad1.20x1.40mm_HandSolder
R2, R3, R4, R5: 5.1k; R_0805_2012Metric_Pad1.20x1.40mm_HandSolder
R6, R9, R10, R11: 10k; R_0805_2012Metric_Pad1.20x1.40mm_HandSolder
SW1, SW2: SW_Push_Dual_x2; SMT_FS
TP1, TP2, TP3, TP4, TP5, TP6, TP7, TP8, TP9: TestPoint; TestPoint_Pad_1.5x1.5mm
U1: AMS1117-3.3; SOT-223-3_TabPin2
U2: ESP32-S3-WROOM-2
U3: LM1084-5.0; TO-263-3_TabPin2
U5: TMP236A4DCKR; SOT-353_SC-70-5_Handsoldering
U6: TSSOP-14-1EP_4.4x5mm_P0.65mm

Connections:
+3.3V: C7.1, C8.1, J4.9, J5.2, R2.1, R3.1, R4.1, R6.1, R10.2, R11.2, U1.2 (VO), U2.2 (3V3), U5.4 (V_{DD}), U6.1 (refA)
+5V: C3.1, C4.1, D6.1 (VDD), J2.8, J5.3, J6.1, R1.1, U3.2 (VO), U6.14 (refB)
+12V: C5.1, C6.1, J3.1, J7.1 (Pin_a1), U3.3 (VI)
GND: C1.1, C2.1, C3.2, C4.2, C5.2, C6.2, C7.2, C8.2, D1.1 (K), D2.1 (K), D3.2 (A2), D4.1 (A1), D5.1 (K), D6.3 (VSS), J1.5 (GND), J1.6 (Shield), J2.2, J2.4, J2.9, J3.2, J4.10, J5.1, J6.2, R9.1, SW1.1 (C), SW2.1 (C), U1.1 (GND), U2.1 (GND), U2.40 (GND), U2.41 (GND), U3.1 (GND), U5.2 (GND), U5.5 (GND), U6.7 (GND)
unnamed: D1.2 (A), R1.2
unnamed: D2.2 (A), R2.2
unnamed: D3.1 (A1), J1.2 (D-), U2.13 (USB_D-/IO19)
unnamed: D4.2 (A2), J1.3 (D+), U2.14 (USB_D+/IO20)
unnamed: D5.2 (A), R5.2
unnamed: D6.4 (DIN), U6.13 (B1)
unnamed: D6.2 (DOUT), J5.10
unnamed 11: D7.2 (A), R4.2; also elsewhere on the board
unnamed 12: D7.1 (K), J2.3, U2.9 (IO16); also elsewhere on the board
unnamed 13: D8.2 (A), R3.2; also elsewhere on the board
unnamed 14: D8.1 (K), J2.1, U2.8 (IO15); also elsewhere on the board
unnamed: J4.1, U2.4 (IO4)
unnamed: J4.2, U2.5 (IO5)
unnamed: J4.3, U2.6 (IO6)
unnamed: J4.4, U2.7 (IO7)
unnamed: J4.5, U2.12 (IO8)
unnamed: J4.6, U2.17 (IO9)
unnamed: J4.7, U2.18 (IO10)
unnamed: J4.8, U2.22 (IO14)
unnamed: J5.4, U2.39 (IO1)
unnamed: J5.5, U2.38 (IO2)
unnamed: J5.6, R6.2, U2.26 (IO45)
unnamed: J5.7, R9.2, U2.16 (IO46)
unnamed: C2.2, J5.8, R11.1, SW2.3 (D), U2.27 (IO0)
unnamed: C1.2, J5.9, R10.1, SW1.3 (D), U2.3 (EN)
unnamed: J6.3, U2.19 (IO11)
unnamed: J6.4, U2.21 (IO13)
unnamed: J6.5, U2.11 (IO18)
unnamed: J7.3 (Pin_b2), J7.4 (Pin_b1), U1.3 (VI)
unnamed: U2.15 (IO3), U5.3 (V_{OUT})
unnamed: U2.20 (IO12), U6.2 (A1)
unnamed: R5.1, U2.10 (IO17)
unnamed: U2.23 (IO21), U6.3 (A2)
unnamed: TP3.1, U2.31 (IO38)
unnamed: TP8.1, U2.24 (IO47)
unnamed: TP9.1, U2.25 (IO48)
unnamed: TP4.1, U2.32 (MTCK/IO39)
unnamed: TP6.1, U2.34 (MTDI/IO41)
unnamed: TP5.1, U2.33 (MTDO/IO40)
unnamed: TP7.1, U2.35 (MTMS/IO42)
unnamed: TP1.1, U2.36 (RXD0/IO44)
unnamed: TP2.1, U2.37 (TXD0/IO43)
unnamed: J2.7, U6.12 (B2)
VBUS: J1.1 (VBUS), J7.2 (Pin_a2)

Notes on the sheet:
5V REGULATION
3V REGULATION

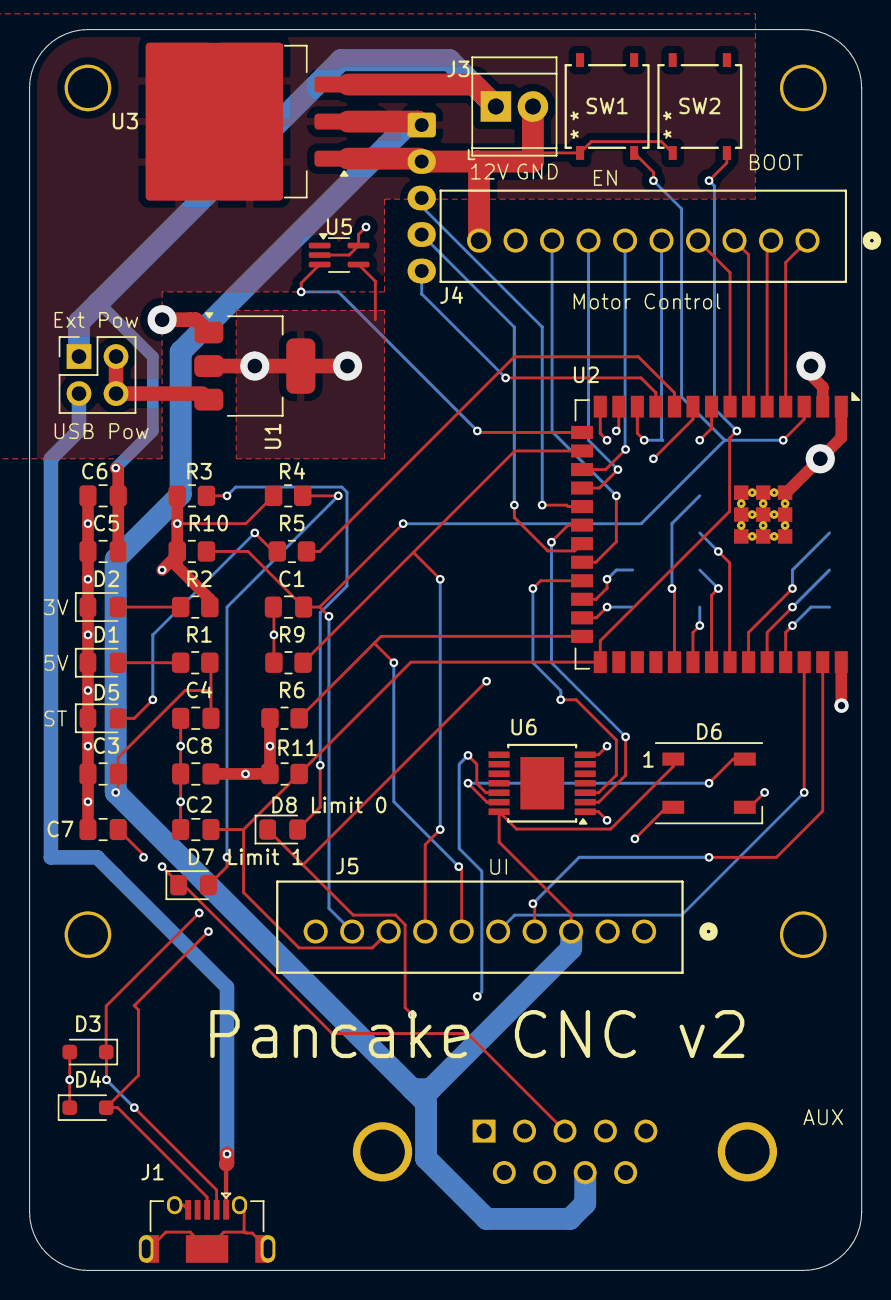
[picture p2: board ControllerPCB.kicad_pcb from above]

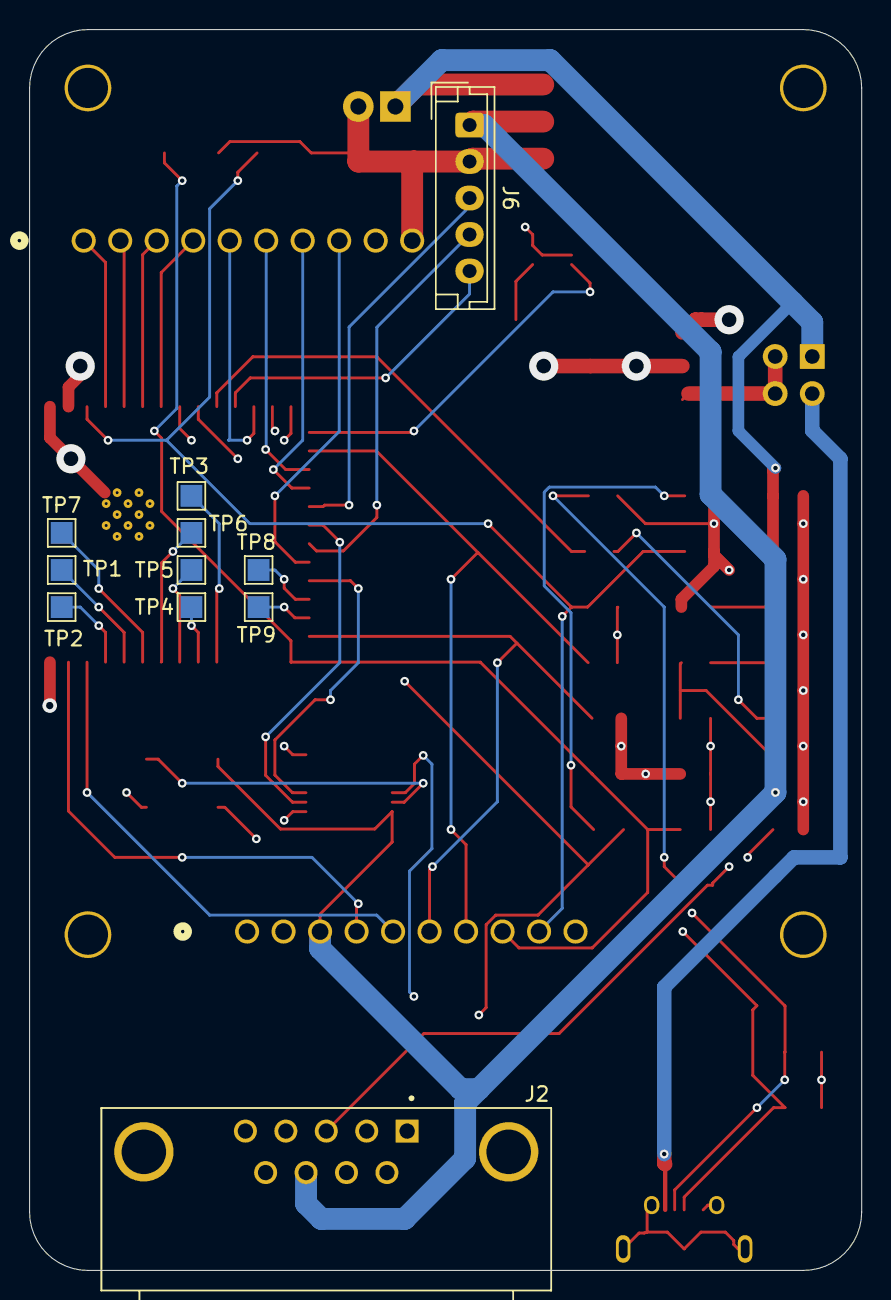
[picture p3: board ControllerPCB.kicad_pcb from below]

Board: 4 copper layers, 57.0 x 85.0 mm, 52 parts (11 on the bottom side), 48 nets.

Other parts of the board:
D7 Limit 1, D8 Limit 0: LED; LED_0805_2012Metric_Pad1.15x1.40mm_HandSolder

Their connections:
unnamed 11: D7 Limit 1.2 (A); also elsewhere on the board
unnamed 12: D7 Limit 1.1 (K); also elsewhere on the board
unnamed 13: D8 Limit 0.2 (A); also elsewhere on the board
unnamed 14: D8 Limit 0.1 (K); also elsewhere on the board

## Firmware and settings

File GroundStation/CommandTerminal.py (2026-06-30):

#!/usr/bin/env python3
"""Interactive terminal for sending commands to an InfluxDB command bucket.

Simplified syntax (no leading / or -a):
  e Hello World
  cnc_spiral CenterX_m=0.2 LinearSpeed_mps=0.05
  wait timeout_ms=500
  cnc_sine Amplitude_deg=10 Frequency_hz=0.25
  cnc_constant_speed S0Speed_degps=0 S1Speed_degps=45
  cnc_rectangle InsetDistance_m=0.01 LinearSpeed_mps=0.05
  cnc_go_to_angle TargetS0_deg=0 TargetS1_deg=0 AngleTolerance_deg=0.25
  cnc_home
  cnc_go_home
  local_origin OriginX_m=0.0 OriginY_m=0.0

Run a newline-delimited program file:
  run_file TestProgram.cake

Env vars: INFLUXDB_URL, INFLUXDB_TOKEN, INFLUXDB_ORG, INFLUXDB_CMD_BUCKET

Commands are encoded as binary [opcode][length][payload] and base64-encoded before being written.
"""

from __future__ import annotations

import base64
import os
import sys
import time
from typing import Optional, Dict, Tuple, Any, List
import shlex
import struct

import re
import glob

# ANSI colors
RESET = "\033[0m"
DIM = "\033[2m"
RED = "\033[31m"
GREEN = "\033[32m"
YELLOW = "\033[33m"
CYAN = "\033[36m"


INFLUXDB_URL = os.environ.get("INFLUXDB_URL")
INFLUXDB_TOKEN = os.environ.get("INFLUXDB_TOKEN")
INFLUXDB_ORG = os.environ.get("INFLUXDB_ORG")
INFLUXDB_CMD_BUCKET = os.environ.get("INFLUXDB_CMD_BUCKET")
_last_write_timestamp_ms = 0

GCODE_DIR = os.path.join(os.path.dirname(os.path.abspath(__file__)), "GCode")
GCODE_FILE_EXTENSION = ".cake"


def _has_path_separator(text: str) -> bool:
    return os.path.basename(text) != text or "/" in text or "\\" in text


OPCODES: Dict[str, Tuple[str, int]] = {  # echo mapping
    "e": ("Echo", 0x69),
}

# CNC opcode mapping (matches current firmware CNCOpCodes.h values)
CNC_OPCODES: Dict[str, int] = {
    "cnc_spiral": 0x11,
    "cnc_jog": 0x12,
    "wait": 0x13,
    "cnc_sine": 0x14,
    "cnc_constant_speed": 0x15,
    "set_motor_limits": 0x16,
    "set_pump_constant": 0x17,
    "cnc_arc": 0x18,
    "pump_purge": 0x19,
    "set_accel_scale": 0x1A,
    "cnc_rectangle": 0x1B,
    "cnc_go_to_angle": 0x1C,
    "cnc_home": 0x1D,
    "cnc_go_home": 0x1E,
    "local_origin": 0x1F,
}

# Immediate control opcodes
IMMEDIATE_OPCODES: Dict[str, int] = {
    "pause": 0x01,
    "resume": 0x02,
    "stop": 0x03,
    "crash_diagnostic": 0x04,
}

# Defaults for command arguments
DEFAULTS = {
    "cnc_spiral": {
        "SpiralConstant_mprad": 0.2,   # user-requested default
        "SpiralRate_radps": 1.0,
        "LinearSpeed_mps": 0.05,
        "CenterX_m": 0.0,
        "CenterY_m": 0.0,
        "MaxRadius_m": 0.0,
    },
    "cnc_sine": {
        "Amplitude_deg": 0.0,
        "Frequency_hz": 0.0,
    },
    "cnc_constant_speed": {
        "S0Speed_degps": 0.0,
        "S1Speed_degps": 0.0,
    },
    "wait": {
        "timeout_ms": 0,
    },
    "cnc_rectangle": {
        "InsetDistance_m": 0.0,
        "LinearSpeed_mps": 0.05,
    },
    "cnc_go_to_angle": {
        "AngleTolerance_deg": 0.25,
    },
}


def print_help() -> None:
    print(f"{CYAN}Commands:{RESET}")
    print("  e <message>")
    print("  cnc_spiral k=v [k=v] [...] or comma-separated")
    print("  cnc_sine k=v [k=v] [...] or comma-separated")
    print("  cnc_constant_speed k=v [k=v] [...] or comma-separated")
    print("  cnc_jog TargetX_m=<m> TargetY_m=<m> LinearSpeed_mps=<m/s> PumpOn=<0|1>")
    print("  cnc_arc StartTheta_rad=<rad> EndTheta_rad=<rad> Radius_m=<m> LinearSpeed_mps=<m/s> CenterX_m=<m> CenterY_m=<m>")
    print("  cnc_rectangle InsetDistance_m=<m> LinearSpeed_mps=<m/s>")
    print("  cnc_go_to_angle TargetS0_deg=<deg> TargetS1_deg=<deg> AngleTolerance_deg=<deg>")
    print("  cnc_home")
    print("  cnc_go_home")
    print("  local_origin OriginX_m=<m> OriginY_m=<m>")
    print("  pump_purge pumpSpeed_degps=<signed deg/s> duration_ms=<ms>")
    print("  wait timeout_ms=<int>")
    print("  set_motor_limits motor=<S0|S1|Pump|All> accel=<degps2> speed=<degps>")
    print("  set_pump_constant pumpConstant_degpm=<val>")
    print("  set_accel_scale accelScale=<ratio>")
    print("  pause | resume | stop")
    print("  crash_diagnostic")
    print("  ask_to_continue [message]")
    print("  terminal_wait duration_ms=<int>")
    print("  run_file <filename.cake> [delay_ms]")
    print("")
    print(f"{DIM}Tip: '<Cmd> help' shows command-specific options.{RESET}")


# Command-specific help text
COMMAND_HELP: Dict[str, str] = {
    "e": "e <message> — Echo a text message.",
    "cnc_spiral": (
        "cnc_spiral keys:\n"
        "  SpiralConstant_mprad: float (default 0.2)\n"
        "  SpiralRate_radps:    float (default 1.0)\n"
        "  LinearSpeed_mps:     float (default 0.05)\n"
        "  CenterX_m:           float\n"
        "  CenterY_m:           float\n"
        "  MaxRadius_m:         float"
    ),
    "cnc_sine": (
        "cnc_sine keys:\n"
        "  Amplitude_deg: float\n"
        "  Frequency_hz:  float"
    ),
    "cnc_constant_speed": (
        "cnc_constant_speed keys:\n"
        "  S0Speed_degps: float\n"
        "  S1Speed_degps: float"
    ),
    "cnc_jog": (
        "cnc_jog keys:\n"
        "  TargetX_m:          float\n"
        "  TargetY_m:          float\n"
        "  LinearSpeed_mps:    float\n"
        "  PumpOn:             0|1"
    ),
    "cnc_arc": (
        "cnc_arc keys:\n"
        "  StartTheta_rad:     float\n"
        "  EndTheta_rad:       float\n"
        "  Radius_m:           float\n"
        "  LinearSpeed_mps:    float\n"
        "Note: Arc center is derived from current position as the start point on the arc."
    ),
    "cnc_rectangle": (
        "cnc_rectangle keys:\n"
        "  InsetDistance_m: float margin from min/max arm reach\n"
        "  LinearSpeed_mps: float"
    ),
    "cnc_go_to_angle": (
        "cnc_go_to_angle keys:\n"
        "  TargetS0_deg:       float absolute stage-0 angle target\n"
        "  TargetS1_deg:       float absolute stage-1 angle target\n"
        "  AngleTolerance_deg: float completion tolerance (default 0.25)"
    ),
    "cnc_home": "cnc_home — calibrate S0/S1 from the limit switches, then return to 0/0.",
    "cnc_go_home": "cnc_go_home — move stages to S0=90, S1=180.",
    "local_origin": (
        "local_origin keys:\n"
        "  OriginX_m: float local X offset added to later cartesian commands\n"
        "  OriginY_m: float local Y offset added to later cartesian commands"
    ),
    "wait": (
        "wait keys:\n"
        "  timeout_ms: int"
    ),
    "set_motor_limits": (
        "set_motor_limits keys:\n"
        "  motor: S0 | S1 | Pump | All\n"
        "  accel: float\n"
        "  speed: float"
    ),
    "set_pump_constant": (
        "set_pump_constant keys:\n"
        "  pumpConstant_degpm: float"
    ),
    "set_accel_scale": (
        "set_accel_scale keys:\n"
        "  accelScale: float — fraction of accel limit to apply"
    ),
    "pump_purge": (
        "pump_purge keys:\n"
        "  pumpSpeed_degps: signed float (deg/s; negative reverses pump)\n"
        "  duration_ms:     int (ms)"
    ),
    "pause": "pause — immediately zero speeds and hold state.",
    "resume": "resume — clear pause and continue.",
    "stop": "stop — idle and clear queued CNC commands.",
    "crash_diagnostic": (
        "crash_diagnostic — print reset/coredump facts to EVR logs, then erase the saved coredump."
    ),
    "ask_to_continue": (
        "ask_to_continue [message]\n"
        "  Prompts the user to continue (y/n). Not sent to device."
    ),
    "terminal_wait": (
        "terminal_wait keys:\n"
        "  duration_ms: int — local delay before next command."
    ),
}

# Legacy command names mapped to canonical snake_case names
CMD_ALIASES: Dict[str, str] = {
    "E": "e",
    "Wait": "wait",
    "Pause": "pause",
    "Resume": "resume",
    "Stop": "stop",
    "CrashDiagnostic": "crash_diagnostic",
    "CNC_Spiral": "cnc_spiral",
    "CNC_Sine": "cnc_sine",
    "CNC_ConstantSpeed": "cnc_constant_speed",
    "CNC_Jog": "cnc_jog",
    "CNC_Arc": "cnc_arc",
    "CNC_Rectangle": "cnc_rectangle",
    "CNC_GoToAngle": "cnc_go_to_angle",
    "CNC_Home": "cnc_home",
    "CNC_GoHome": "cnc_go_home",
    "SetMotorLimits": "set_motor_limits",
    "SetPumpConstant": "set_pump_constant",
    "SetAccelScale": "set_accel_scale",
    "PumpPurge": "pump_purge",
    "LocalOrigin": "local_origin",
    "SetLocalOrigin": "local_origin",
}

def _canonical_cmd_name(cmd: str) -> str:
    return CMD_ALIASES.get(cmd, cmd)


def print_command_help(cmd: str) -> bool:
    txt = COMMAND_HELP.get(_canonical_cmd_name(cmd))
    if txt:
        print(txt)
        return True
    return False


def _require(env: Optional[str], name: str) -> str:
    if not env:
        print(f"Environment variable {name} must be set", file=sys.stderr)
        sys.exit(1)
    return env


def _build_echo_packet(message: str) -> bytes:
    opcode = OPCODES["e"][1]
    data = message.encode("utf-8")
    if len(data) > 255:
        raise ValueError("message too long for single-byte length field")
    return bytes([opcode, len(data)]) + data


def _build_pump_purge_payload(args: Dict[str, Any]) -> bytes:
    allowed = {"pumpSpeed_degps", "duration_ms"}
    unknown = set(args.keys()) - allowed
    if unknown:
        raise ValueError(f"Unknown keys for pump_purge: {', '.join(sorted(unknown))}")
    speed_degps = float(args.get("pumpSpeed_degps"))
    duration_ms = int(args.get("duration_ms"))
    return struct.pack("<fi", speed_degps, duration_ms)


def _build_cnc_payload(cmd: str, args: Dict[str, Any]) -> Tuple[int, bytes]:
    if cmd not in CNC_OPCODES:
        raise ValueError(f"Unknown CNC command: {cmd}")
    op = CNC_OPCODES[cmd]

    merged = {**DEFAULTS.get(cmd, {}), **args}

    if cmd == "cnc_spiral":
        allowed = {"SpiralConstant_mprad", "SpiralRate_radps", "LinearSpeed_mps", "CenterX_m", "CenterY_m", "MaxRadius_m"}
        unknown = set(args.keys()) - allowed
        if unknown:
            raise ValueError(f"Unknown keys for cnc_spiral: {', '.join(sorted(unknown))}")
        payload = struct.pack(
            "<ffffff",
            float(merged.get("SpiralConstant_mprad")),
            float(merged.get("SpiralRate_radps")),
            float(merged.get("LinearSpeed_mps")),
            float(merged.get("CenterX_m")),
            float(merged.get("CenterY_m")),
            float(merged.get("MaxRadius_m")),
        )
        return op, payload
    elif cmd == "cnc_sine":
        allowed = {"Amplitude_deg", "Frequency_hz"}
        unknown = set(args.keys()) - allowed
        if unknown:
            raise ValueError(f"Unknown keys for cnc_sine: {', '.join(sorted(unknown))}")
        payload = struct.pack(
            "<ff",
            float(merged.get("Amplitude_deg")),
            float(merged.get("Frequency_hz")),
        )
        return op, payload
    elif cmd == "cnc_constant_speed":
        allowed = {"S0Speed_degps", "S1Speed_degps"}
        unknown = set(args.keys()) - allowed
        if unknown:
            raise ValueError(f"Unknown keys for cnc_constant_speed: {', '.join(sorted(unknown))}")
        payload = struct.pack(
            "<ff",
            float(merged.get("S0Speed_degps")),
            float(merged.get("S1Speed_degps")),
        )
        return op, payload
    elif cmd == "wait":
        allowed = {"timeout_ms"}
        unknown = set(args.keys()) - allowed
        if unknown:
            raise ValueError(f"Unknown keys for wait: {', '.join(sorted(unknown))}")
        payload = struct.pack("<i", int(merged.get("timeout_ms")))
        return op, payload
    elif cmd == "set_motor_limits":
        # Expect: motor=S0|S1|Pump|All accel=... speed=...
        motor_map = {"S0": 0, "S1": 1, "Pump": 2, "All": 255}
        mkey = str(args.get("motor", "All"))
        motor_id = motor_map.get(mkey, 255)
        accel = float(args.get("accel", 0.0))
        speed = float(args.get("speed", 0.0))
        allowed = {"motor", "accel", "speed"}
        unknown = set(args.keys()) - allowed
        if unknown:
            raise ValueError(f"Unknown keys for set_motor_limits: {', '.join(sorted(unknown))}")
        payload = struct.pack("<Bff", motor_id, accel, speed)
        return op, payload
    elif cmd == "set_pump_constant":
        allowed = {"pumpConstant_degpm"}
        unknown = set(args.keys()) - allowed
        if unknown:
            raise ValueError(f"Unknown keys for set_pump_constant: {', '.join(sorted(unknown))}")
        val = float(args.get("pumpConstant_degpm", 0.0))
        payload = struct.pack("<f", val)
        return op, payload
    elif cmd == "set_accel_scale":
        allowed = {"accelScale"}
        unknown = set(args.keys()) - allowed
        if unknown:
            raise ValueError(f"Unknown keys for set_accel_scale: {', '.join(sorted(unknown))}")
        val = float(args.get("accelScale", 0.0))
        payload = struct.pack("<f", val)
        return op, payload
    elif cmd == "cnc_jog":
        allowed = {"TargetX_m", "TargetY_m", "LinearSpeed_mps", "PumpOn"}
        unknown = set(args.keys()) - allowed
        if unknown:
            raise ValueError(f"Unknown keys for cnc_jog: {', '.join(sorted(unknown))}")
        tx = float(args.get("TargetX_m"))
        ty = float(args.get("TargetY_m"))
        sp = float(args.get("LinearSpeed_mps", 0.05))
        pump = int(args.get("PumpOn", 0))
        payload = struct.pack("<fffI", tx, ty, sp, pump)
        return op, payload
    elif cmd == "cnc_arc":
        allowed = {"StartTheta_rad", "EndTheta_rad", "Radius_m", "LinearSpeed_mps", "CenterX_m", "CenterY_m"}
        unknown = set(args.keys()) - allowed
        if unknown:
            raise ValueError(f"Unknown keys for cnc_arc: {', '.join(sorted(unknown))}")
        start = float(args.get("StartTheta_rad"))
        end = float(args.get("EndTheta_rad"))
        r = float(args.get("Radius_m"))
        sp = float(args.get("LinearSpeed_mps"))
        cx = float(args.get("CenterX_m"))
        cy = float(args.get("CenterY_m"))
        payload = struct.pack("<ffffff", start, end, r, sp, cx, cy)
        return op, payload
    elif cmd == "cnc_rectangle":
        allowed = {"InsetDistance_m", "LinearSpeed_mps"}
        unknown = set(args.keys()) - allowed
        if unknown:
            raise ValueError(f"Unknown keys for cnc_rectangle: {', '.join(sorted(unknown))}")
        inset = float(merged.get("InsetDistance_m"))
        sp = float(merged.get("LinearSpeed_mps"))
        payload = struct.pack("<ff", inset, sp)
        return op, payload
    elif cmd == "cnc_go_to_angle":
        allowed = {"TargetS0_deg", "TargetS1_deg", "AngleTolerance_deg"}
        unknown = set(args.keys()) - allowed
        if unknown:
            raise ValueError(f"Unknown keys for cnc_go_to_angle: {', '.join(sorted(unknown))}")
        s0 = float(args.get("TargetS0_deg"))
        s1 = float(args.get("TargetS1_deg"))
        tol = float(merged.get("AngleTolerance_deg"))
        payload = struct.pack("<fff", s0, s1, tol)
        return op, payload
    elif cmd in {"cnc_home", "cnc_go_home"}:
        if args:
            raise ValueError(f"{cmd} does not take arguments")
        return op, b""
    elif cmd == "local_origin":
        allowed = {"OriginX_m", "OriginY_m"}
        unknown = set(args.keys()) - allowed
        if unknown:
            raise ValueError(f"Unknown keys for local_origin: {', '.join(sorted(unknown))}")
        payload = struct.pack("<ff", float(args.get("OriginX_m", 0.0)), float(args.get("OriginY_m", 0.0)))
        return op, payload
    elif cmd == "pump_purge":
        return op, _build_pump_purge_payload(args)
    else:
        raise ValueError(f"No payload builder for {cmd}")


def _parse_kv_tokens(tokens: List[str]) -> Dict[str, Any]:
    flat: List[str] = []
    for tok in tokens:
        for piece in tok.split(','):
            s = piece.strip()
            if s:
                flat.append(s)
    out: Dict[str, Any] = {}
    for item in flat:
        if '=' not in item:
            raise ValueError(f"Bad arg: {item}")
        k, v = item.split('=', 1)
        k = k.strip()
        v = v.strip()
        try:
            if v.lower().startswith(('0x', '-0x')):
                out[k] = int(v, 16)
            else:
                out[k] = int(v)
        except ValueError:
            try:
                out[k] = float(v)
            except ValueError:
                out[k] = v
    return out

def _build_command_packet(line: str) -> Optional[bytes]:
    parts = shlex.split(line)
    if not parts:
        return None
    cmd_raw = parts[0]
    cmd = cmd_raw
    if len(parts) >= 2 and parts[1].lower() in {"help", "-h", "?"}:
        # handled by caller
        return None
    if cmd == "run_file":
        return None
    # Normalize command names to snake_case
    cmd = _canonical_cmd_name(cmd_raw)
    if cmd == "e":
        msg = line[len(parts[0]):].lstrip()
        return _build_echo_packet(msg)

    if cmd in IMMEDIATE_OPCODES:
        return bytes([IMMEDIATE_OPCODES[cmd], 0])

    arg_map = _parse_kv_tokens(parts[1:])

    opcode, payload = _build_cnc_payload(cmd, arg_map)
    if len(payload) > 255:
        raise ValueError("payload too long")
    return bytes([opcode, len(payload)]) + payload


def _run_file_path_candidates(text: str) -> List[str]:
    """Return filename completions for .cake programs in the GCode directory."""
    if _has_path_separator(text):
        return []

    candidates = set()
    pattern = os.path.join(GCODE_DIR, text + "*")
    try:
        matches = glob.glob(pattern)
    except Exception:
        return []

    for match in matches:
        if os.path.isfile(match) and match.endswith(GCODE_FILE_EXTENSION):
            candidates.add(os.path.basename(match))

    return sorted(candidates)


def _resolve_run_file_path(file_name: str) -> str:
    if not file_name or file_name in {".", ".."} or _has_path_separator(file_name):
        raise ValueError("run_file expects a file name in GroundStation/GCode, not a path")
    if not file_name.endswith(GCODE_FILE_EXTENSION):
        raise ValueError("run_file expects a .cake file name in GroundStation/GCode")
    return os.path.abspath(os.path.join(GCODE_DIR, file_name))


def _write_packet(packet: bytes) -> None:
    import requests
    global _last_write_timestamp_ms

    url = f"{INFLUXDB_URL}/api/v2/write"
    params = {
        "org": INFLUXDB_ORG,
        "bucket": INFLUXDB_CMD_BUCKET,
        "precision": "ms",
    }
    headers = {
        "Authorization": f"Token {INFLUXDB_TOKEN}",
        "Content-Type": "text/plain",
    }
    b64 = base64.b64encode(packet).decode("ascii")
    timestamp = int(time.time() * 1000)
    if timestamp <= _last_write_timestamp_ms:
        timestamp = _last_write_timestamp_ms + 1
    _last_write_timestamp_ms = timestamp
    line = f"cmd data=\"{b64}\" {timestamp}"
    resp = requests.post(url, params=params, data=line, headers=headers, timeout=5)
    resp.raise_for_status()


def _run_file(path: str, delay_ms: int, run_file_stack: Optional[List[str]] = None) -> None:
    stack = run_file_stack if run_file_stack is not None else []
    abs_path = _resolve_run_file_path(path)
    if abs_path in stack:
        chain = " -> ".join([*stack, abs_path])
        raise ValueError(f"Recursive run_file call disallowed: {chain}")

    stack.append(abs_path)
    try:
        with open(abs_path, 'r', encoding='utf-8') as f:
            for raw in f:
                s = raw.strip()
                if not s or s.startswith('#'):
                    continue
                # Local-only handling for file-driven commands
                parts2 = shlex.split(s)
                cmd2 = parts2[0] if parts2 else ''
                if cmd2 == 'ask_to_continue':
                    msg = s[len(cmd2):].strip()
                    prompt = msg if msg else 'Continue? (y/n): '
                    # Show the script line
                    print(f"{DIM}↳ {s}{RESET}")
                    while True:
                        resp = input(prompt).strip().lower()
                        if resp in {'y', 'yes'}:
                            break
                        if resp in {'n', 'no'}:
                            print("Aborted by user.")
                            return
                        print("Please respond with 'y' or 'n'.")
                    continue
                if cmd2 == 'terminal_wait':
                    kv = _parse_kv_tokens(parts2[1:])
                    if 'duration_ms' not in kv:
                        raise ValueError("terminal_wait requires duration_ms=<int>")
                    dur = int(kv['duration_ms'])
                    print(f"{DIM}↳ {s}{RESET}")
                    time.sleep(max(0, dur) / 1000.0)
                    continue
                if cmd2 == 'run_file':
                    print(f"{DIM}↳ {s}{RESET}")
                    _send_command(s, stack)
                    continue

                pkt = _build_command_packet(s)

                if pkt is not None:
                    # Show file-driven lines in a muted style
                    print(f"{DIM}↳ {s}{RESET}")
                    _write_packet(pkt)
                    time.sleep(delay_ms / 1000.0)
    finally:
        stack.pop()
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

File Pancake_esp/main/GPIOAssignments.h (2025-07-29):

// GPIOAssignments.h
#ifndef GPIOASSIGNMENTS_H
#define GPIOASSIGNMENTS_H

#include "driver/gpio.h"

#define ALIVE_LED GPIO_NUM_17
#define ADDRESSABLE_LEDS GPIO_NUM_21

// MOTOR CONTROL
#define S1_MOTOR_PULSE GPIO_NUM_7
#define S1_MOTOR_DIR GPIO_NUM_8

#define S0_MOTOR_PULSE GPIO_NUM_9
#define S0_MOTOR_DIR GPIO_NUM_10
#define S0S1_MOTOR_ENABLE GPIO_NUM_14

#define PUMP_MOTOR_PULSE GPIO_NUM_4
#define PUMP_MOTOR_DIR GPIO_NUM_5
#define PUMP_MOTOR_ENABLE GPIO_NUM_6

// Define UART configuration
#define UART_NUM UART_NUM_2
#define UART_TX_PIN 11
#define UART_RX_PIN 13

// UI and limit switches
#define S0_LIMIT_SWITCH GPIO_NUM_16
#define S1_LIMIT_SWITCH GPIO_NUM_15

#define POT_X_CHANNEL ADC_CHANNEL_0 // GPIO1 TODO correct these three
#define POT_Y_CHANNEL ADC_CHANNEL_1 // GPIO2
#define TEMP_CHANNEL ADC_CHANNEL_2  // GPIO3

#endif // GPIOAssignments

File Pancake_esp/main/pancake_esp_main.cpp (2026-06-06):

#include "StepperMotor.h"
#include "defines.h"
#include "MotorControl.h"
#include "WifiHandler.h"
#include "InfluxDBCmdAndTlm.h"
#include "CrashDebug.h"
#include "PanMath.h"

namespace
{
void PrintReachableRectangleCorners()
{
    Vector2D corners_m[4];
    if (!GetReachableRectangleCorners(corners_m))
    {
        ESP_LOGE("TO1P", "Reachable rectangle corners unavailable");
        return;
    }

    ESP_LOGI("TO1P", "Reachable rectangle corners (m):");
    for (int corner = 0; corner < 4; corner++)
    {
        ESP_LOGI("TO1P", "  corner %d: x=%.4f, y=%.4f", corner + 1, corners_m[corner].x,
                 corners_m[corner].y);
    }
}
} // namespace

extern "C"
{

#include "Safety.h"
//#include "UI.h"

    void app_main(void)
    {
        CrashDebugPrintResetReason();
        ESP_LOGI("TO1P", "Free heap: %lu bytes", esp_get_free_heap_size());
        PrintReachableRectangleCorners();

        esp_log_level_set("wifi", ESP_LOG_WARN);

        // Safety first
        SafetyInit();
        SafetyStart();

        // Initialize the tasks

        //  UIInit();
        MotorControlInit();
        WifiInit();
        CmdAndTlmInit();

        // Start the tasks
        vTaskDelay(pdMS_TO_TICKS(5000));
        CrashDebugPrintResetReason();
        CmdAndTlmStart();
        CrashDebugPrintResetReason();
        // UIStart();

        // Energize the CNC last
        MotorControlStart(); 

    }
}

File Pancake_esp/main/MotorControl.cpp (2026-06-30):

#include "MotorControl.h"
#include "AngleMotion.h"
#include "MotorCommandRouter.h"
#include "MotorControlState.h"
#include "HomingController.h"
#include "JogGuidance.h"
#include "ArcGuidance.h"
#include "RectangleGuidance.h"
#include "GoToAngleGuidance.h"
#include "GuidanceRegistry.h"
#include "CNCOpCodes.h"
#include "MotionSafety.h"
#include "Safety.h"

#include <cmath>
#include <cstring>

const char *TAG = "CNCControl";

motor_tlm_t LocalS0Tlm;
motor_tlm_t LocalS1Tlm;
motor_tlm_t LocalPumpTlm;

Vector2D Pos_m{0.0f, 0.0f};
Vector2D Vel_mps{0.0f, 0.0f};
Vector2D Target_m{0.0f, 0.0f};
Vector2D LocalOrigin_m{0.0f, 0.0f};

bool CNCEnabled = false;
static bool EStopActive = false;

// CNC instructions now arrive via cmd_queue_cnc (decoded_cmd_payload_t)

const float motor_step_size_deg = 0.9 / 16.0; // TODO, track down 16 error term
static constexpr float S0_LIMIT_ANGLE_DEG = 210.0 - 17.0;
static constexpr float S1_LIMIT_ANGLE_DEG = -180.0f;
static constexpr float GO_HOME_S0_ANGLE_DEG = 120.0f;
static constexpr float GO_HOME_S1_ANGLE_DEG = -115.0f;
static constexpr float DEFAULT_ANGLE_TOLERANCE_DEG = 0.25f;
static constexpr AngleMotion::KeepOutZoneDeg S0_KEEP_OUT_ZONE_DEG{210.0f, 300.0f};
static constexpr AngleMotion::TravelBoundsDeg S1_TRAVEL_BOUNDS_DEG{-270.0f, 270.0f};
static constexpr AngleMotion::AngleMoveLimitsDeg S0_ANGLE_LIMITS_DEG{
    true, S0_KEEP_OUT_ZONE_DEG, false, {0.0f, 0.0f}};
static constexpr AngleMotion::AngleMoveLimitsDeg S1_ANGLE_LIMITS_DEG{
    false, {0.0f, 0.0f}, true, S1_TRAVEL_BOUNDS_DEG};

// Create motor instances
// Step size = gear ratio * motor step size / micro step reduction
static StepperMotor S0Motor(S0_MOTOR_PULSE, S0_MOTOR_DIR, 800.0, 50.0, motor_step_size_deg * 16.0 / 108.0,
                            "S0MOTOR",false);
static StepperMotor S1Motor(S1_MOTOR_PULSE, S1_MOTOR_DIR, 800.0, 50.0, motor_step_size_deg * 10.0 / 24.0,
                            "S1MOTOR", true);
static StepperMotor PumpMotor(PUMP_MOTOR_PULSE, PUMP_MOTOR_DIR, 10.0, 600, motor_step_size_deg, "PUMPMOTOR", true);

static bool ResolveJogPumpEnabled(const GeneralGuidance &guidance)
{
    return static_cast<const JogGuidance &>(guidance).Config.PumpOn != 0;
}

static bool ApplyGoHomeGuidanceConfig(GeneralGuidance &guidance, const uint8_t *payload)
{
    (void)payload;
    GoToAngleConfig config{GO_HOME_S0_ANGLE_DEG, GO_HOME_S1_ANGLE_DEG, DEFAULT_ANGLE_TOLERANCE_DEG};
    static_cast<GoToAngleGuidance &>(guidance).ApplyConfig(config);
    return true;
}

struct LocalOriginConfig
{
    float OriginX_m;
    float OriginY_m;
};

static void ApplyLocalOriginToCartesianConfig(uint8_t opcode, uint8_t *payload, Vector2D localOrigin_m)
{
    if (opcode == CNC_JOG_OPCODE)
    {
        JogConfig *config = reinterpret_cast<JogConfig *>(payload);
        config->TargetX_m += localOrigin_m.x;
        config->TargetY_m += localOrigin_m.y;
    }
    else if (opcode == CNC_ARC_OPCODE)
    {
        ArcConfig *config = reinterpret_cast<ArcConfig *>(payload);
        config->CenterX_m += localOrigin_m.x;
        config->CenterY_m += localOrigin_m.y;
    }
    else if (opcode == CNC_SPIRAL_OPCODE)
    {
        SpiralConfig *config = reinterpret_cast<SpiralConfig *>(payload);
        config->CenterX_m += localOrigin_m.x;
        config->CenterY_m += localOrigin_m.y;
    }
}

static void LogGuidanceLoadError(const GuidanceLoadError &error)
{
    if (!error.opcodeKnown)
    {
        ESP_LOGE(TAG, "Unknown OpCode: 0x%02X", error.opcode);
        return;
    }

    ESP_LOGE(TAG, "Invalid payload length for OpCode 0x%02X: expected %u got %u",
             error.opcode, (unsigned)error.expectedPayloadLength, (unsigned)error.actualPayloadLength);
}

static void ApplyStoppedHold(MotorControlState &state, MotorCommandRouter &commandRouter,
                             Vector2D currentPosition_m, float currentS0_deg, float currentS1_deg,
                             const char *reason)
{
    MotionHoldCommand stopCommand = MakeStoppedHoldCommand(currentPosition_m, currentS0_deg, currentS1_deg);
    ApplyHoldCommand(state, stopCommand);

    int drained = stopCommand.clearCommandQueue ? commandRouter.DrainCncCommandQueue() : 0;
    ESP_LOGW(TAG, "%s: cleared %d queued commands", reason, drained);
}

static bool ApplyLimitStopIfBlocked(MotorControlState &state, MotorCommandRouter &commandRouter,
                                    Vector2D currentPosition_m, float currentS0_deg,
                                    float currentS1_deg, float requestedS0_deg,
                                    float requestedS1_deg,
                                    const AngleMotion::AngleMovePlan &s0Plan,
                                    const AngleMotion::AngleMovePlan &s1Plan,
                                    const char *mode)
{
    if (s0Plan.blocked)
    {
        ESP_LOGE(TAG, "S0 %s move %.2f -> requested %.2f crosses keep-out %.2f..%.2f deg",
                 mode, currentS0_deg, requestedS0_deg,
                 S0_KEEP_OUT_ZONE_DEG.start_deg, S0_KEEP_OUT_ZONE_DEG.end_deg);
        ApplyStoppedHold(state, commandRouter, currentPosition_m, currentS0_deg, currentS1_deg,
                         "S0 limit stop");
        return true;
    }

    if (s1Plan.blocked)
    {
        ESP_LOGE(TAG, "S1 %s move %.2f -> requested %.2f exceeds travel bounds %.2f..%.2f deg",
                 mode, currentS1_deg, requestedS1_deg,
                 S1_TRAVEL_BOUNDS_DEG.min_deg, S1_TRAVEL_BOUNDS_DEG.max_deg);
        ApplyStoppedHold(state, commandRouter, currentPosition_m, currentS0_deg, currentS1_deg,
                         "S1 limit stop");
        return true;
    }

    return false;
}

static void RefreshLocalTelemetryAndPosition(MotorControlState &state)
{
    PumpMotor.GetTlm(&LocalPumpTlm);
    S0Motor.GetTlm(&LocalS0Tlm);
    S1Motor.GetTlm(&LocalS1Tlm);

    AngToCart(LocalS0Tlm.Position_deg, LocalS1Tlm.Position_deg, LocalS0Tlm.Speed_degps,
              LocalS1Tlm.Speed_degps, state.currentPosition_m, state.currentVelocity_mps);
    Pos_m = state.currentPosition_m;
    Vel_mps = state.currentVelocity_mps;
}

void MotorControlInit()
{
    // Hardware initialization

    // Set pulse pins.  The safety component will handle the enable pins
    gpio_reset_pin(PUMP_MOTOR_PULSE);
    gpio_set_direction(PUMP_MOTOR_PULSE, GPIO_MODE_OUTPUT);

    gpio_reset_pin(PUMP_MOTOR_DIR);
    gpio_set_direction(PUMP_MOTOR_DIR, GPIO_MODE_OUTPUT);

    // Initialize timers for each motor
    S0Motor.InitializeTimers(MOTOR_CONTROL_PERIOD_MS);
    S1Motor.InitializeTimers(MOTOR_CONTROL_PERIOD_MS);
    PumpMotor.InitializeTimers(MOTOR_CONTROL_PERIOD_MS);

    // Copy local tlm
    PumpMotor.GetTlm(&LocalPumpTlm);
    S0Motor.GetTlm(&LocalS0Tlm);
    S1Motor.GetTlm(&LocalS1Tlm);

    AngToCart(LocalS0Tlm.Position_deg, LocalS1Tlm.Position_deg, Pos_m);
    Target_m = Pos_m;
}

void MotorControlStart() { xTaskCreate(MotorControlTask, TAG, 10000, NULL, 1, NULL); }
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

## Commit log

2024-11-08 Initial check in. Basic motor control functionality and experimental serial interface
2024-11-08 Fixed pi to esp32 cmd bug
    [MotorControl.cpp]
2024-11-10 Motor control dev
2024-11-16 Check in first rev of controller pcb
    [ControllerPCB-B_Cu.gbr, ControllerPCB-B_Mask.gbr, ControllerPCB-B_Paste.gbr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]
2024-11-17 Rev 2 of controller PCB
    [ControllerPCB-B_Cu.gbl, ControllerPCB-B_Cu.gbr, ControllerPCB-B_Mask.gbr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]
2024-11-17 Configure the limit switches
2024-11-17 Setup motor enable / disable commanding and limit switch handling
2024-11-18 Implement temperature sensing
    [ControllerPCB.kicad_pcb]
2024-12-15 Initial guidance and geometry controls
    [PumpBase.stl, PumpSpinner.stl, PumpTop.stl]
2025-05-26 Update buildspec for motor control
2025-05-26 Progress save. Bug in motor control or pan math. CNC out of bounds error
    [MotorControl.cpp, Safety.c, StepperMotor.cpp]
2025-06-02 Can no longer sprial. Memory issue in how instruction set is configured, used
    [ArchimedeanSpiral.cpp, MotorControl.cpp, StepperMotor.cpp]
2025-06-15 Correct enable pin hadling and publish limit switch tlm
    [MotorControl.cpp, Safety.c]
2025-06-26 Added in pump control, cleanup
2025-07-05 Create sine CNC guidance to debug steppers
2025-07-12 Add homing capabilities, zeroing, constant angle rate commands
2025-07-29 Bug fixes and tuning from system test
    [ArchimedeanSpiral.cpp, GPIOAssignments.h, MotorControl.cpp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]
2025-07-30 Remove TlmPublisher AI slop. Refactor and setup framework for influxdb based commanding
    [InfluxDBCmdAndTlm.cpp, pancake_esp_main.cpp]
2025-07-31 Sometimes connects to wifi before crashing
    [pancake_esp_main.cpp]
2025-07-31 Add bounds checks for UART protocol
2025-08-24 Removed erroneous esp_error check, left modem power saving state a default
2025-09-02 Fix and centralize InfluxDB CSV parsing
    [InfluxDBCmdAndTlm.cpp]
2025-09-17 Wrap motor angle commands to shortest path
    [MotorControl.cpp]
2025-09-17 Fix build errors, check in pump flow gcode
2025-10-18 Clean up repo
    [PumpBase.stl, PumpSpinner.stl, PumpTop.stl]
2025-10-18 docs: align readme with current hardware
2026-06-04 Fix out of bounds logic
    [MotorControl.cpp]
2026-06-06 Reversable pump
2026-06-06 Add pump rev
2026-06-20 Works ok, stop reboot persists
    [CommandTerminal.py, HomingController.h, InfluxDBCmdAndTlm.cpp]
